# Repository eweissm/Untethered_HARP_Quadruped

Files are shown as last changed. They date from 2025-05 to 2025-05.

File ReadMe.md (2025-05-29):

# Open-Sourced HARP-Driven Untethered Quadruped

**Author:** Eric Weissman  
**Last Updated:** May 2025

This repository contains all design files, simulation tools, and documentation needed to build and test an untethered quadruped robot actuated by HARP-driven pneumatic legs.

---

##  Bill of Materials (BOM)

- A complete list of components and part numbers is provided in:  
  **`BOM.xls`**

---

## 🛠 CAD Files

- Full mechanical assembly in STEP format:  
  **`CAD Files/LongLegQuadAssembly Final.STEP`**

- Use any CAD software that supports `.STEP` files (e.g., SolidWorks, Fusion 360, FreeCAD) to view or modify.

---

##  Simulation

- MATLAB simulation model of a single leg is provided in:  
  **`Simulation/QuadLegModel_5_1.m`**

- This model uses **Peter Corke's Robotics Toolbox** for MATLAB.  
  Please install it before running the simulation:  
  [Peter Corke's Robotics Toolbox](https://petercorke.com/toolboxes/robotics-toolbox/)

---

##  Electronics

- Custom controller PCB design is provided in Eagle format:  
  **`Electronics/Quadruped+Board.zip`**

- Includes:
  - `.brd` and `.sch` Eagle design files
  - Part placements and annotations

- Compatible with Autodesk Eagle and Fusion 360 Electronics.

---

##  Directory Structure

```plaintext
├── BOM.xls
├── CAD Files/
│   └── LongLegQuadAssembly Final.STEP
├── Simulation/
│   └── QuadLegModel_5_1.m
├── Electronics/
│   └── Quadruped+Board.zip

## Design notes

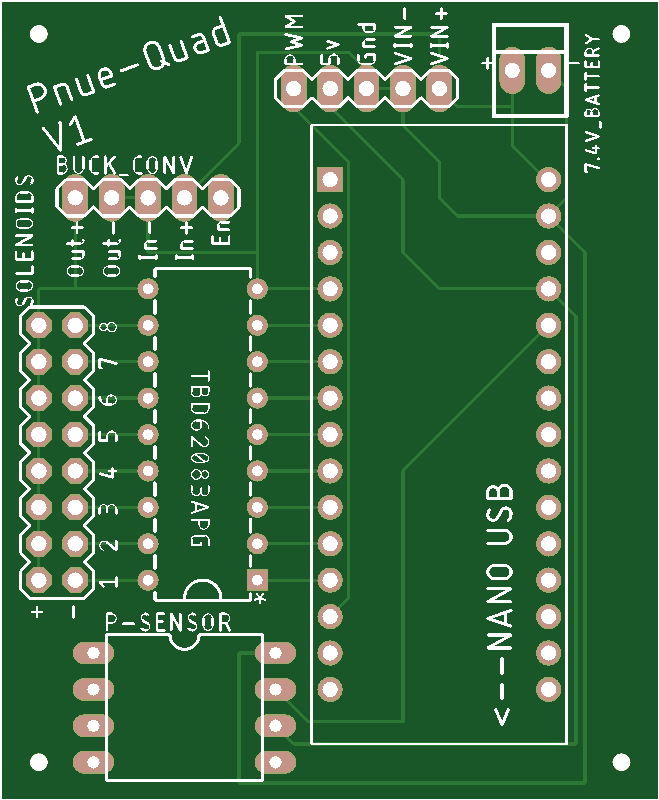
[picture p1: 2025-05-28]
Electronics/Board.png

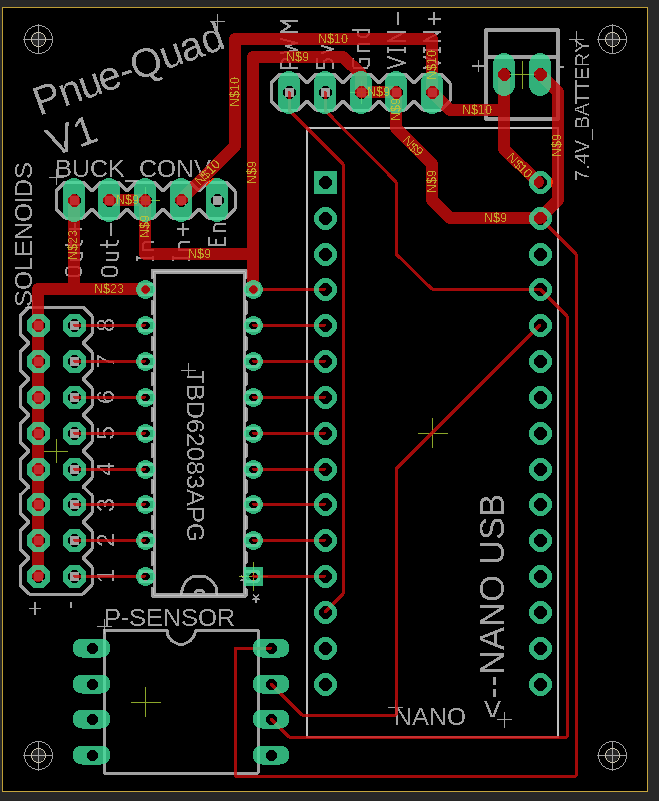
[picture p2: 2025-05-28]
Electronics/Board_Eagle.png

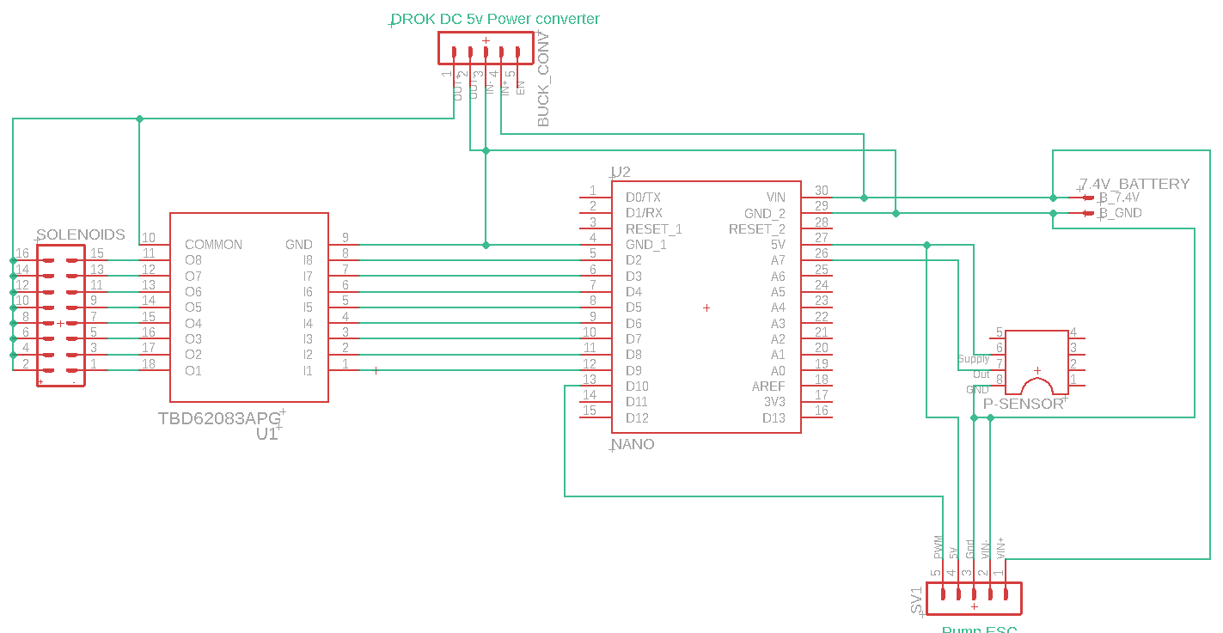
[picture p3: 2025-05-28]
Electronics/Schematic.png

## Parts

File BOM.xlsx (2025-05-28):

 | HARP Untethered Quadruped BOM
 | Part No. | Part Name | Quantity | Sourcing | NOTE:
Mechanical Hardware | 1 | M2 Heat Stake Insert | 1 | https://www.amazon.com/HANGLIFE-Heat-Set-Threaded-Printing-Components/dp/B0CS6XJSSL
 | 2 | Carbon Fiber Shank (Frame_Center, Frame_Back, Frame_Front, Frame_side, Femur, Tibia) | 2 | https://www.amazon.com/gp/product/B0BX93VLDQ/ref=ox_sc_act_image_4?smid=A37EFSP4QP9HL5&psc=1 | cut to lengths: 2x 285mm, 1x265mm, 4x 125mm, 8x145mm
 | 3 | M2 set screws | 1 | https://www.amazon.com/iExcell-Stainless-Steel-Socket-Screws/dp/B094NT6K3N?pid=vd80ZjB&s=industrial
 | 4 | M2 nuts | 1 | https://www.amazon.com/uxcell-M2x0-4mm-Coarse-Thread-Hexagon/dp/B07H3TGLB8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
 | 5 | M3 Nuts and Bolts | 1 | https://www.amazon.com/Assortment-Stainless-Replacement-Machine-Fastener/dp/B0BMQFHDBH?s=industrial
 | 6 | PLA filament | 1 | https://www.amazon.com/ELEGOO-Filament-Dimensional-Accuracy-Cardboard/dp/B0BM739JRF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
Pneumatic Hardware | 7 | Buffer Tank | 1 | https://robart.com/collections/air-systems-components-air-tanks/products/x-small-pressure-tank
 | 8 | Soft Tubing (1/16" x1/8" Tygon Tube) | 10 ft | https://www.mcmaster.com/8349T12/
 | 9 | HARP Luer Fitting ("1/8- female) | 4 packs of 10 | https://www.amazon.com/MEETOOT-Laboratory-Biochemical-Analytical-Instruments/dp/B09PTX6M2Z?s=industrial
 | 10 | HARP End Caps | 4 packs of 10 | https://www.mcmaster.com/5463K74/
 | 11 | Parker X-valves | 5 | https://ph.parker.com/us/en/product/x-valve-miniature-pneumatic-solenoid-valve/912-000001-031
 | 12 | Piston Pump | 1 | https://www.amazon.com/ROCKBROS-Electric-Portable-Inflator-Aluminium/dp/B0C77398NP?xpid=3p1rf8Ar-ysOO | Piston Pump is to be removed from the larger assembly
 | 13 | 1/16" t-joint | 2 | https://www.mcmaster.com/5463K43/
 | 14 | 1/16" cross joint | 2 | https://www.mcmaster.com/5463K91/
 | 15 | Leur lock- 3 way valve | 1 | https://www.amazon.com/gp/product/B0CNPWH95P/ref=ox_sc_act_title_1?smid=A9D8YXTOGXF1I&psc=1
 | 16 | Luer Barb (1'/16" male) | 4 packs of 10 | https://www.amazon.com/MEETOOT-Polycarbonate-Laboratory-Biochemical-Instruments/dp/B0BXX3GRMX
Electronics | 17 | Circuit Board | 1 | https://cart.jlcpcb.com/quote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
 | 18 | Arduino Nano | 1 | https://www.amazon.com/LAFVIN-Board-ATmega328P-Micro-Controller-Arduino/dp/B07G99NNXL
 | 19 | Pressure Sensor (4525-SS5A100GP) | 1 | https://www.digikey.com/en/products/detail/te-connectivity-measurement-specialties/4525-SS5A100GP/3569042
 | 20 | BLDC motor Driver | 1 | ESC: 20A ESC Brushless Electronic Speed Controller DSHOT BLHeli_S 2-4S Lipo https://www.amazon.com/dp/B09F3GLKBG?ref=fed_asin_title | Make Sure to reprogram the driver so LVC is deactivated
 | 21 | Battery | 1 | https://www.amazon.com/dp/B07MTDCTCD?ref=fed_asin_title&th=1
 | 22 | Switch | 1 | https://www.amazon.com/TWTADE-Solder-Rocker-Switch-KCD1-X-Y/dp/B07XC5KB8D?s=industrial
 | 23 | Transistor Array (TBD62083APG) | 1 | https://www.digikey.com/en/products/detail/toshiba-semiconductor-and-storage/TBD62083APG/5514089
 | 24 | Boost Converter | 1 | https://www.amazon.com/Converter-DROK-Transformer-Adjustable-Stabilizer/dp/B096RC71DC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
HARP Materials | 25 | Silicone Tube (5/32x3/32) | 50 ft | https://www.mcmaster.com/5296N11-5296N17/
 | 26 | Nylon Core (.032") | 1 | https://www.mcmaster.com/9442T101/
 | 27 | Ecoflex 00-10 | 1 | https://www.amazon.com/Ecoflex-00-10-Super-Soft-Addition-Silicone/dp/B06XPN1HVH
3d Printed Parts | 28 | FrameCore | 1 | 3d Printed (FDM printed)
 | 29 | Gluteus Extensor Mount | 8
 | 30 | MuscleMount_Back | 16
 | 31 | MuscleMount_Back_3Muscles | 16
 | 32 | MuscleMount 3Muscle | 16
 | 33 | MuscleMount | 16
 | 34 | CrossBeam Bracket | 2
 | 35 | CrossBeam Bracket_Leftfront | 2
 | 36 | MotorClip | 1
 | 37 | QuadrupedOnBoardPackageMount_lowweight | 1
 | 38 | Parker Valve Mount | 1
 | 39 | Parker Valve Mount plate | 1
 | 40 | CenterFrameBrackets | 2
 | 41 | Gluteus Extensor body Mount | 4
 | 42 | 2d-foot | 4
 | 43 | KneeJoint_Lower_strong | 4
 | 44 | Gluteus Extensor Mount LONG_bent | 4
 | 45 | KneeJoint_Upper | 4
 | 46 | HipJoint_Strong | 4
 | 47 | ShaftCollar_longLeg | 4
 | 48 | KneeJoint_Lower_LowWeight | 4
 | 49 | RightFrontHip | 2
 | 50 | LeftFrontHip | 2

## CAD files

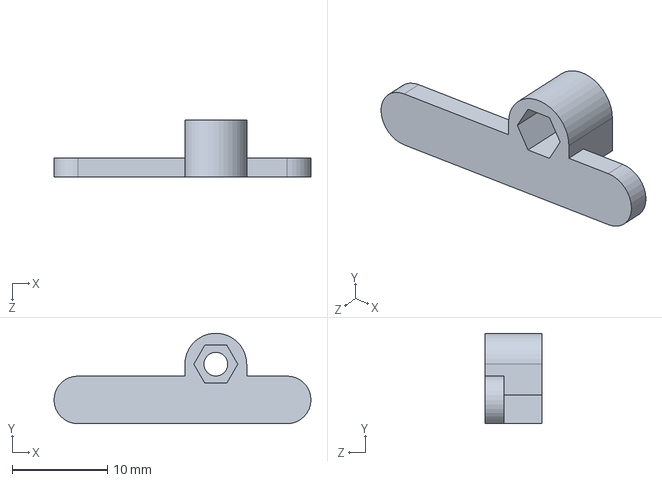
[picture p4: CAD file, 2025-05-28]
CAD Files/MuscleMount_Back 3Muscles.SLDPRT
27.0 x 9.49 x 6.00 mm

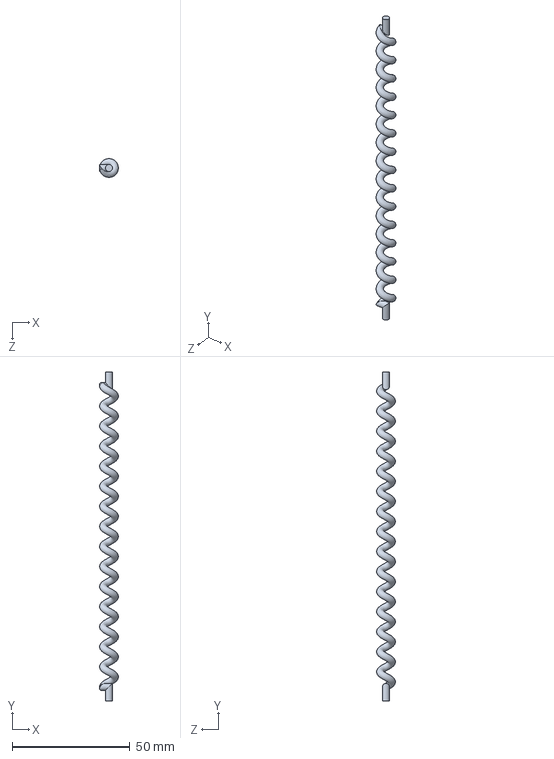
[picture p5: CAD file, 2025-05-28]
CAD Files/HARP_configurable.SLDPRT
8.00 x 140.0 x 8.00 mm

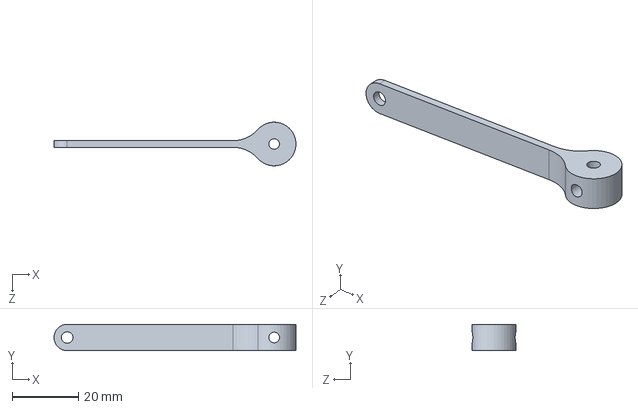
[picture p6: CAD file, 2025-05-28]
CAD Files/Gluteus Extensor Mount.SLDPRT
73.1 x 8.00 x 13.2 mm

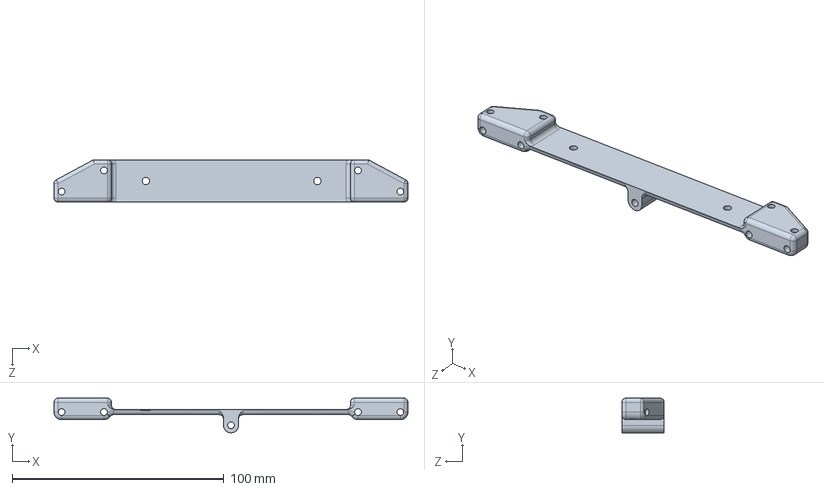
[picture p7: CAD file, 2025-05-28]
CAD Files/FrameCore.SLDPRT
167.2 x 16.5 x 20.0 mm

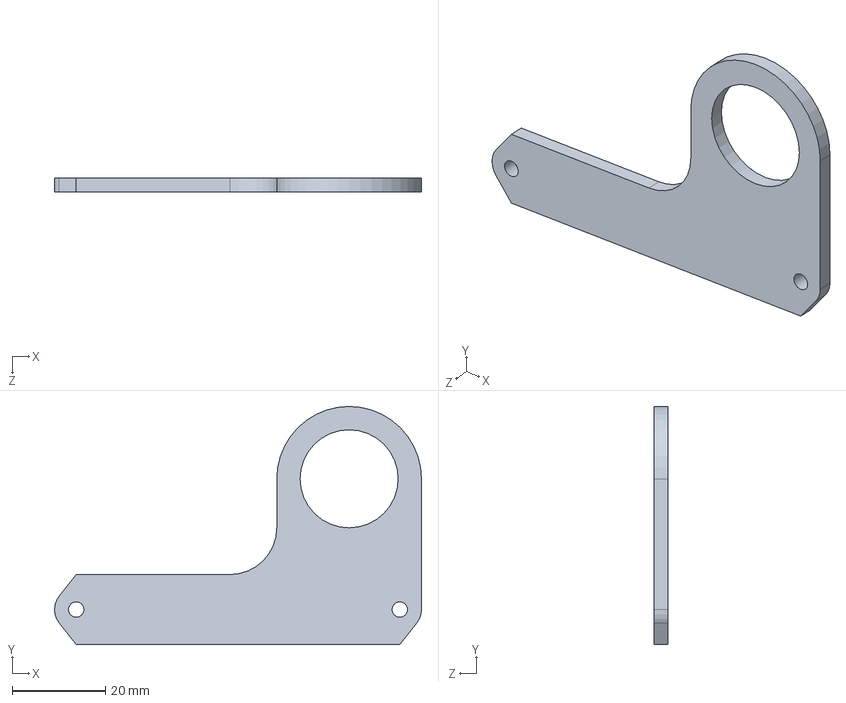
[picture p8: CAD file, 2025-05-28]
CAD Files/motorClip.SLDPRT
78.6 x 51.0 x 3.00 mm

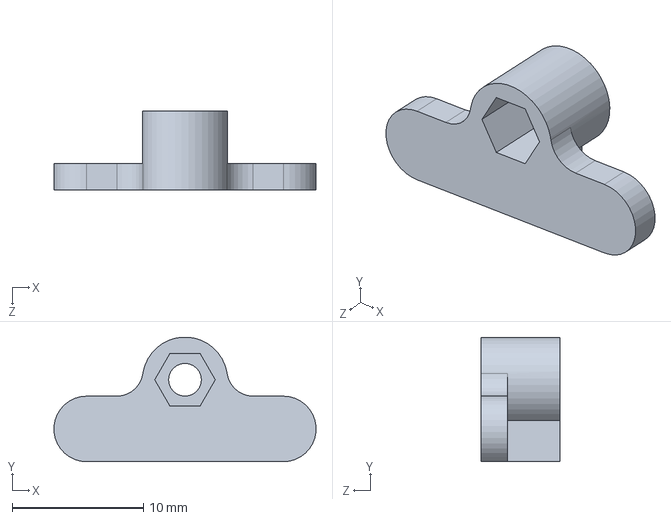
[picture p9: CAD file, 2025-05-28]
CAD Files/MuscleMount_Back.SLDPRT
20.0 x 9.49 x 6.00 mm

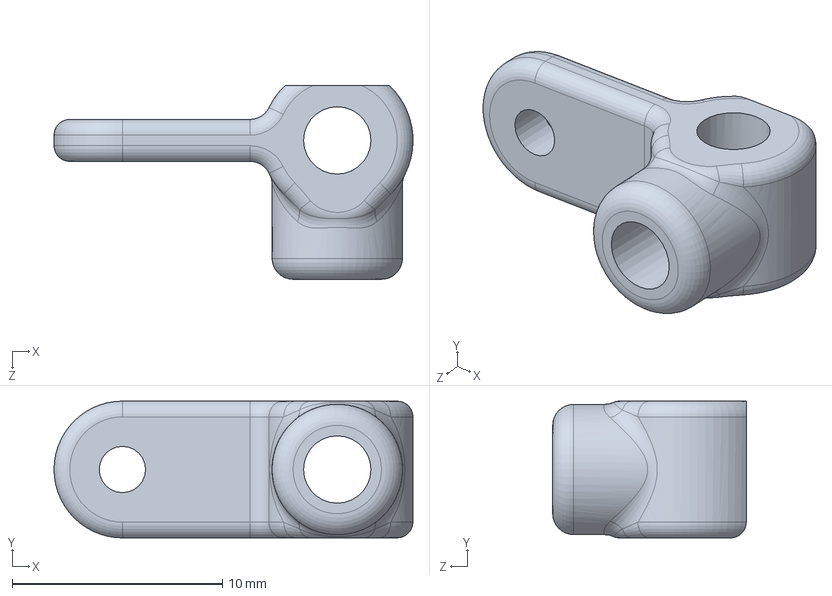
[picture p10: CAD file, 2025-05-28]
CAD Files/Knee Joint_ Lower_LowWeight.SLDPRT
17.1 x 6.50 x 9.20 mm

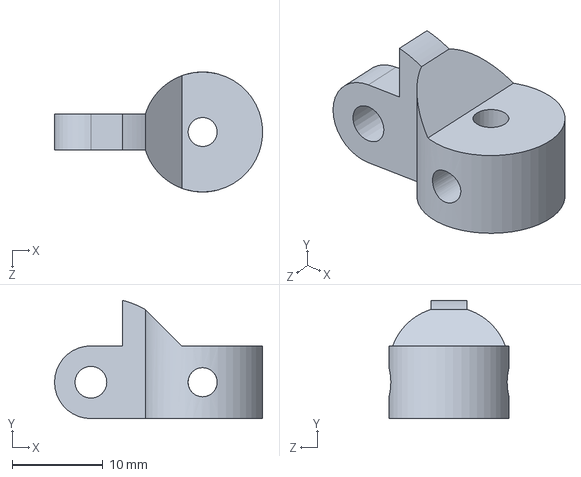
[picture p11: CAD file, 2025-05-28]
CAD Files/Knee Joint_ Lower_strong.SLDPRT
22.9 x 13.0 x 13.2 mm

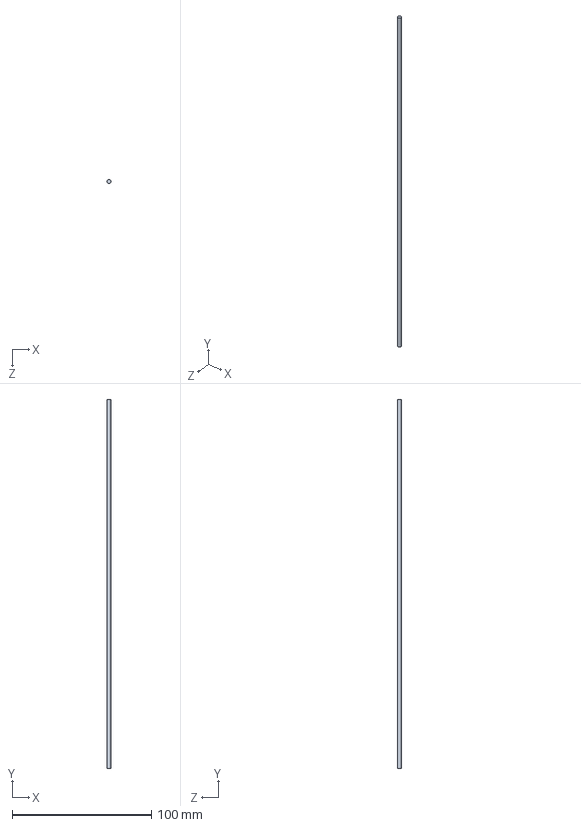
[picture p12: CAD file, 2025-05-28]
CAD Files/Frame_Center.SLDPRT
3.00 x 265.0 x 3.00 mm

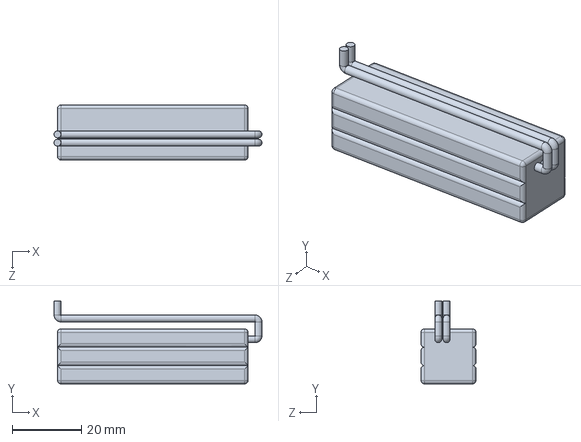
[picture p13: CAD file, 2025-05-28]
CAD Files/Battery.SLDPRT
60.0 x 23.9 x 15.9 mm

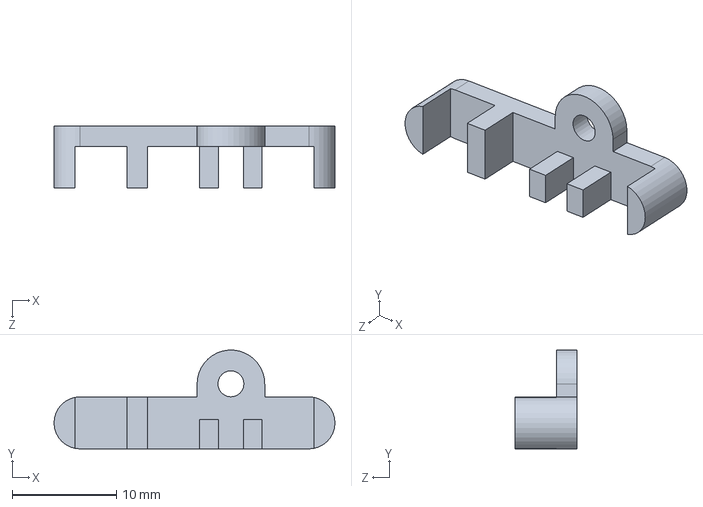
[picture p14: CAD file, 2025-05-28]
CAD Files/MuscleMount 3Muscle.SLDPRT
27.0 x 9.49 x 6.00 mm

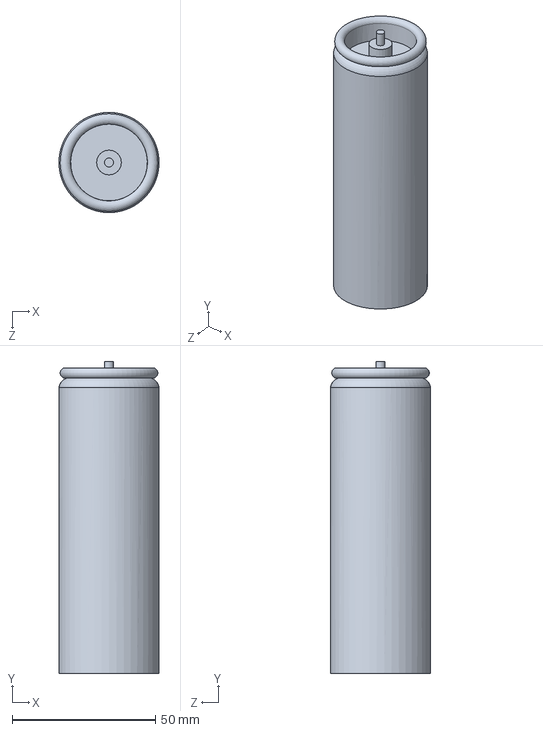
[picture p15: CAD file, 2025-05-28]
CAD Files/Tank.SLDPRT
35.0 x 109.0 x 35.0 mm

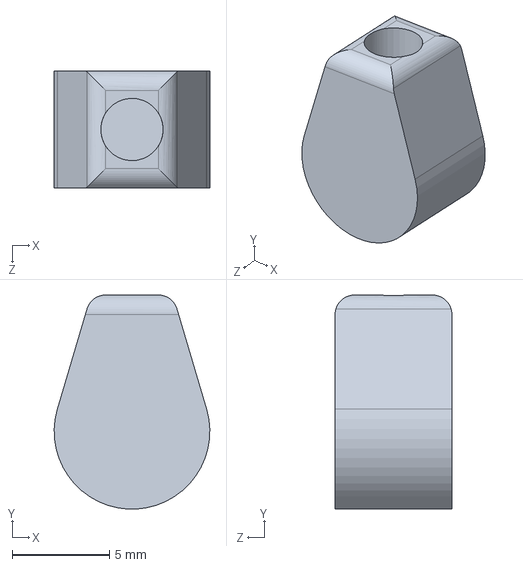
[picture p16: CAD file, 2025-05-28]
CAD Files/2d-foot.SLDPRT
8.00 x 11.0 x 6.00 mm

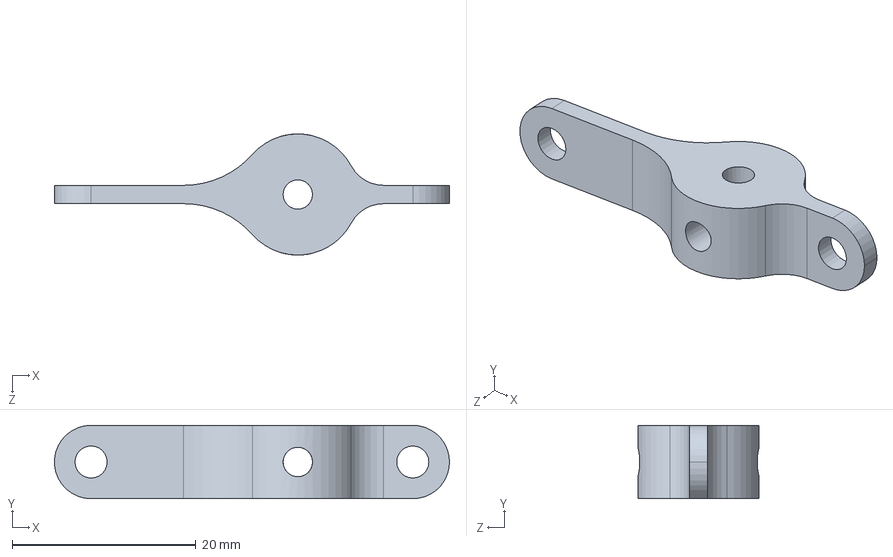
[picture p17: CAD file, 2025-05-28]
CAD Files/Gluteus Extensor body Mount.SLDPRT
43.0 x 8.00 x 13.2 mm

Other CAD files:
CAD Files/MirrorKnee Joint_ Upper.SLDPRT
CAD Files/MirrorKnee Joint_ Lower_LowWeight.SLDPRT
CAD Files/MirrorMuscleMount.SLDPRT
CAD Files/Frame_CrossBeam.SLDPRT
CAD Files/5111K751_Push-to-Connect Tube Fitting for Air and Water.SLDPRT
CAD Files/7395K127_Rocker Switch.SLDPRT
CAD Files/CenterFrameBrackets.SLDPRT
CAD Files/CrossBeam Bracket.SLDPRT
CAD Files/CrossBeam Bracket_Left front.SLDPRT
CAD Files/Femur.SLDPRT
CAD Files/Frame_Back.SLDPRT
CAD Files/Frame_Front.SLDPRT
CAD Files/Frame_Side.SLDPRT
CAD Files/Gluteus Extensor Mount LONG_bent.SLDPRT
CAD Files/HipJoint_ Strong.SLDPRT
CAD Files/Knee Joint_ Upper.SLDPRT
CAD Files/LeftFrontHip.SLDPRT
CAD Files/Mirror2d-foot.SLDPRT
CAD Files/MirrorFemur.SLDPRT
CAD Files/MirrorGluteus Extensor Mount LONG_bent.SLDPRT
CAD Files/MirrorGluteus Extensor Mount.SLDPRT
CAD Files/MirrorGluteus Extensor body Mount.SLDPRT
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
